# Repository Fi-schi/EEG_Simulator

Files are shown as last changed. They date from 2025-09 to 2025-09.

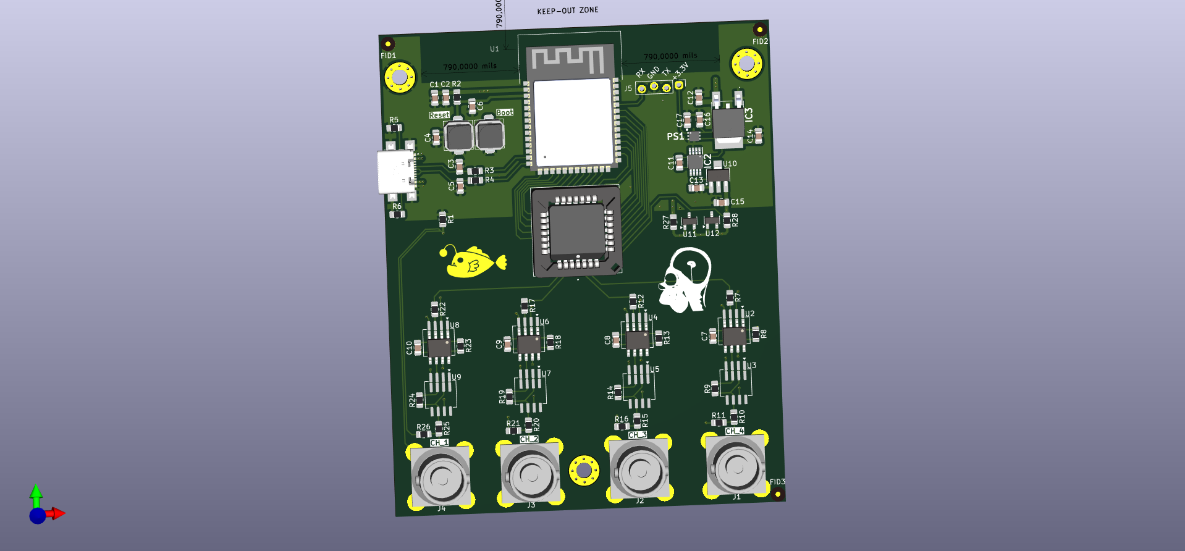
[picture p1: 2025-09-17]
hardware/EEG-Simulator-Platine/EEG-Simulator-Platine.png

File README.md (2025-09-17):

# EEG-Simulator

Ein Projektseminar an der Hochschule Wismar zur **Entwicklung eines
EEG-Signalgenerators**. 
Ziel ist es, eine kompakte, intuitive und didaktisch nutzbare Plattform
zur Erzeugung synthetischer EEG-Signale bereitzustellen.

## Features

-   4 analoge Ausgangskanäle für simultane Signalwiedergabe 
-   Steuerung über einen **ESP32-S3 Mikrocontroller** 
-   Hochauflösender DAC (**DAC8412FPZ**) mit 12-Bit Auflösung 
-   Benutzerfreundliche **Weboberfläche** zur Signalverwaltung 
-   Upload eigener Signaldateien über WLAN 
-   Signale im Mikrovoltbereich durch Tiefpassfilter & Spannungsteiler 
-   Keine zusätzliche Softwareinstallation erforderlich (Bedienung im
    Browser)

## Architektur

-   **Hardware**
    -   ESP32-S3 Mikrocontroller (Steuerung, WLAN, Webserver)
    -   DAC8412FPZ (Digital-Analog-Wandler, 4 Kanäle)
    -   TL071CDR Operationsverstärker (aktive Tiefpassfilter)
    -   Spannungsversorgung über USB-C, mit ±5 V und 3,3 V Regulierung
-   **Software**
    -   Frontend: HTML, CSS, JavaScript (Single Page Application)
    -   Backend: ESP32-Firmware in C++ (PlatformIO, ESPAsyncWebServer)
    -   Dateiverwaltung & Signalzuweisung über Webinterface
    -   DAC-Steuerung und Echtzeit-Signalausgabe

## Getting Started

1.  Platine über **USB-C** mit Strom versorgen 
2.  Verbindung mit dem WLAN **EEGsimulator** (Passwort:
    `EEGsimulator2525`) 
3.  Browser öffnen und `192.168.4.1` eingeben 
4.  Über die Weboberfläche:
    -   Signaldateien (`.txt`) hochladen 
    -   Dateien Kanälen zuweisen 
    -   „Verarbeitung anstoßen" und anschließend „Abspielen" klicken

## Dateiformat für Signale

-   Textdateien mit Zahlenwerten (positive/negative Amplituden) 
-   Automatische Skalierung auf den **12-Bit Wertebereich (0--4095)** 
-   Mapping:
    -   Negative Werte → 0--2047 
    -   Positive Werte → 2048--4095

## Hinweise

-   Für stabile Ausgabe eine saubere Stromversorgung sicherstellen 
-   Signale lassen sich per Oszilloskop überwachen 
-   Änderungen an Reihenfolge oder Kanälen erfordern erneute
    Verarbeitung

## Ausblick

-   Verbesserte analoge Filter (z. B. Sallen-Key) 
-   Optimierte Stromversorgung (LDOs oder Akkubetrieb) 
-   Bibliothek vordefinierter EEG-Signalformen (Alpha-/Beta-Wellen
    etc.) 
-   Live-Visualisierung der Signale direkt im Browser

------------------------------------------------------------------------

Entwickelt von **Johannes Fischer** im Rahmen des Projektseminars an
der **Hochschule Wismar**

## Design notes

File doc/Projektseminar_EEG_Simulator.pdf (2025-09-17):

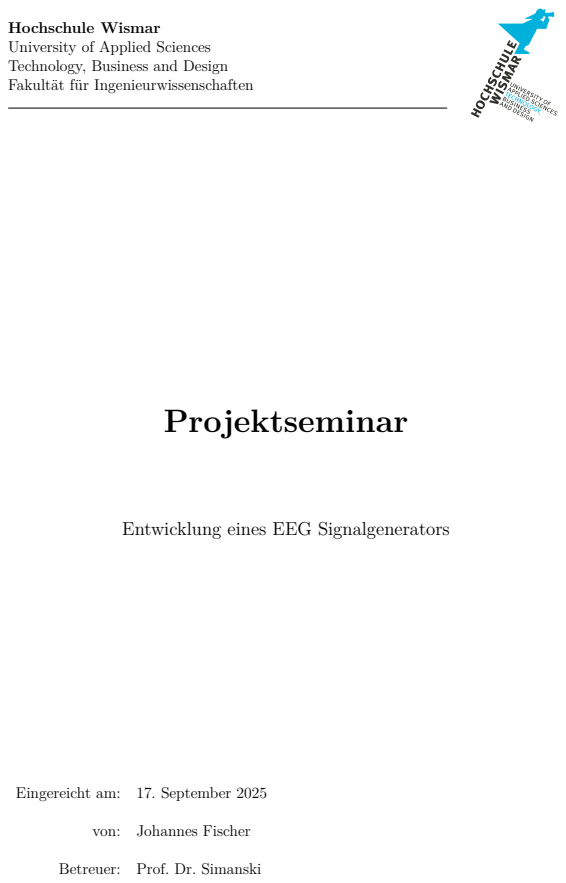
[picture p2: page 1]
Projektseminar

Hochschule Wismar
University of Applied Sciences
Technology, Business and Design
Fakultät für Ingenieurwissenschaften

Entwicklung eines EEG Signalgenerators

Eingereicht am: 17. September 2025

von: Johannes Fischer
Betreuer: Prof. Dr. Simanski

Kurzfassung

Kurzfassung

Im Rahmen des Projektseminars wurde eine Demonstrationsplatine zur Erzeugung synthetischer EEG-Signale entwickelt. Ziel war es, ein kompaktes und intuitiv bedienbares System zu realisieren, das insbesondere im naturwissenschaftlich-technischen Unterricht zum Einsatz kommen kann. Die Signalverarbeitung übernimmt ein ESP32-S3 Mikrocontroller, der über eine parallele Schnittstelle einen hochauflösenden DAC (DAC8412FPZ) ansteuert. Die vier analogen Ausgangskanäle ermöglichen die gleichzeitige Ausgabe mehrerer Signalverläufe. Die Konfiguration der Signale erfolgt benutzerfreundlich über eine integrierte Weboberfläche, die ohne zusätzliche Softwareinstallation über WLAN erreichbar ist. Der Aufbau der Schaltung wurde so gewählt, dass die Signale durch Tiefpassfilter geglättet und über Spannungsteiler optional auf den Mikrovoltbereich skaliert werden können. Während der Erprobung zeigte sich, dass sich die Ausgabequalität durch den Einsatz zusätzlicher Filter- oder Versorgungskomponenten weiter optimieren lässt. Die entwickelte Platine bietet eine solide Basis für didaktische Zwecke sowie eine flexible Plattform für zukünftige Erweiterungen, etwa zur Visualisierung der DAC-Ausgabe im Browser oder zur Einbindung von Signalbibliotheken.

Abstract

In the context of a project seminar, a demonstration printed circuit board (PCB) was developed for the purpose of generating synthetic electroencephalograms (EEGs). The objective of the project was to design a compact and user-friendly system suitable for use in science and engineering education. The generation of signals is facilitated by an ESP32-S3 microcontroller, which governs a high-resolution DAC (DAC8412FPZ) through a parallel interface. It is evident that the four analog output channels facilitate the simultaneous playback of multiple signal patterns. The configuration of the signal is managed through a built-in web interface that is accessible via Wi-Fi and does not require the installation of additional software. The circuit design incorporates low-pass filters for signal smoothing and optional voltage dividers for scaling to microvolt levels. As the testing process unfolded, it became evident that the quality of output could be further enhanced through the implementation of advanced filtration techniques and optimisation of the power supply. The developed system provides a robust foundation for educational applications and a flexible platform for future expansions, such as browser-based signal visualization or the integration of predefined signal libraries.

Inhaltsverzeichnis

### Inhaltsverzeichnis

1 Einleitung | 4
2 Platine | 5
3 Software | 15
4 Bedienung | 18
5 Zusammenfassung und Ausblick | 20
Abbildungsverzeichnis | 22
Selbstständigkeitserklärung | 23

Kapitel 1. Einleitung

### 1 Einleitung

Im Rahmen dieses Projektseminars wurde eine elektronische Schaltung (Platine) entwickelt, die synthetisch generierte EEG-Signale über vier analoge Ausgänge bereitstellen kann. Ziel ist die Bereitstellung eines anschaulichen Demonstrationssystems für den Einsatz im naturwissenschaftlich-technischen Unterricht. Die Signalverarbeitung erfolgt über einen Mikrocontroller, der die digitalen Muster erzeugt und diese über einen Digital-Analog-Wandler (DAC) in analoge Signale umwandelt. Zur Ausgabe stehen vier EEG-Kanäle zur Verfügung, denen die Signale gezielt zugewiesen werden können. Ein weiterer Bestandteil des Projekts ist die Entwicklung eines Webinterfaces, das über die WLAN-Schnittstelle des Mikrocontrollers erreichbar ist. Über die Benutzeroberfläche lassen sich die Signalparameter gezielt einstellen sowie die Kanalzuweisung der Signale verwalten. Zur Visualisierung der generierten Signale wird ein Oszilloskop verwendet, das die analoge Ausgabe in Echtzeit darstellt.

### 1.1 Zielsetzung und Anforderungen

Ziel dieses Kapitels ist die Darstellung der technischen Anforderungen und der strukturellen Umsetzung der entwickelten Platine. Die Schaltung dient als Demonstrationsund Lehrgerät zur Veranschaulichung synthetisch erzeugter EEG-Signale im schulischen oder hochschulischen Unterricht. Kernziel der Platine ist die Erzeugung und analoge Ausgabe von EEG-Signalen über vier getrennte Kanäle. Die Parametrierung der Signale erfolgt über eine browserbasierte Benutzeroberfläche, die ohne zusätzliche Softwareinstallation genutzt werden kann. Die gesamte Steuerung und Ausgabe wird durch einen Mikrocontroller übernommen, der sowohl die Signalverarbeitung als auch die Bereitstellung der Weboberfläche realisiert. Zur Sicherstellung einer realistischen Signalform und zur Rauschunterdrückung kommen ein hochauflösender Digital-Analog-Wandler sowie nachgeschaltete analoge Tiefpassfilter zum Einsatz. Zusätzlich wird das Ausgangssignal über einen Spannungsteiler skaliert, um typische EEG-Signalpegel im Mikrovoltbereich darzustellen. Die folgenden Abschnitte beschreiben die eingesetzten Komponenten, ihre Auswahlkriterien und die Umsetzung auf der entwickelten Platine.

Kapitel 2. Platine

### 2 Platine

### 2.1 Komponentenübersicht

Für die Umsetzung der Platine wurden gezielt Bauteile ausgewählt, die eine zuverlässige Signalverarbeitung sowie eine einfache Integration in ein schulisches Umfeld ermöglichen. Die wichtigsten Hardwarekomponenten sind:
- Mikrocontroller: ESP32-S3 16R8 – steuert die gesamte Signalverarbeitung, erzeugt die digitalen Datenmuster und stellt die Weboberfläche über WLAN bereit.
- Digital-Analog-Wandler (DAC): DAC8412FPZ – ermöglicht die hochauflösende, analoge Ausgabe der zuvor digital berechneten EEG-Signale auf vier unabhängigen Kanälen.
- Operationsverstärker: TL071CDR – dient als aktiver Tiefpassfilter (1. Ordnung) mit einer Verstärkung von 1 zur Glättung der analogen Ausgangssignale.
- Spannungsversorgung:
– NCV1117DT50: Linearregler zur Bereitstellung einer stabilisierten 5-V-Spannung für den DAC und nachgeschaltete Stufen.
– USB-C-Buchse: Dient sowohl der Stromversorgung als auch der optionalen Datenverbindung während der Entwicklung.

### 2.1.1 Hardwarekonzept

Der Mikrocontroller ESP32-S3 16R8 bildet das zentrale Steuerelement der Platine. Er verfügt über zwei Prozessorkerne, wodurch sich die Verarbeitung von Signalmustern und die Bereitstellung der Weboberfläche auf getrennte Kerne verteilen lassen. Mit 16 MB integriertem Flash-Speicher bietet er zudem ausreichend Kapazität zur Ablage von Firmware, Webdateien und Nutzdaten.
Für die analoge Signalausgabe wird der Digital-Analog-Wandler DAC8412FPZ von Analog Devices eingesetzt. Dieser 12-Bit-DAC besitzt vier voneinander unabhängige Ausgänge und wird über eine parallele 16-Bit-Schnittstelle angesteuert. Die

Ansteuerung ermöglicht eine hohe Datenrate und unterstützt somit eine nahezu echtzeitfähige Signalübertragung.
Zur Nachbearbeitung der DAC-Ausgabe wird ein aktiver Tiefpassfilter auf Basis des Operationsverstärkers TL071CDR verwendet. Dieser glättet die Treppenspannung des DACs und unterdrückt hochfrequentes Rauschen, um ein möglichst sauberes analoges Ausgangssignal zu erzeugen.
Die Spannungsversorgung der Komponenten wird durch mehrere Regler bereitgestellt: Ein Linearregler (LDO) liefert 5 V für den DAC und nachgeschaltete Stufen, ein weiterer LDO stellt 3,3 V für den Mikrocontroller bereit. Zusätzlich erzeugt ein invertierender DC/DC-Wandler die negative Versorgungsspannung, sodass der DAC und die Operationsverstärker symmetrisch mit ±5 V betrieben werden können.

### 2.2 Schaltungsdesign

### 2.2.1 Gesamtüberblick

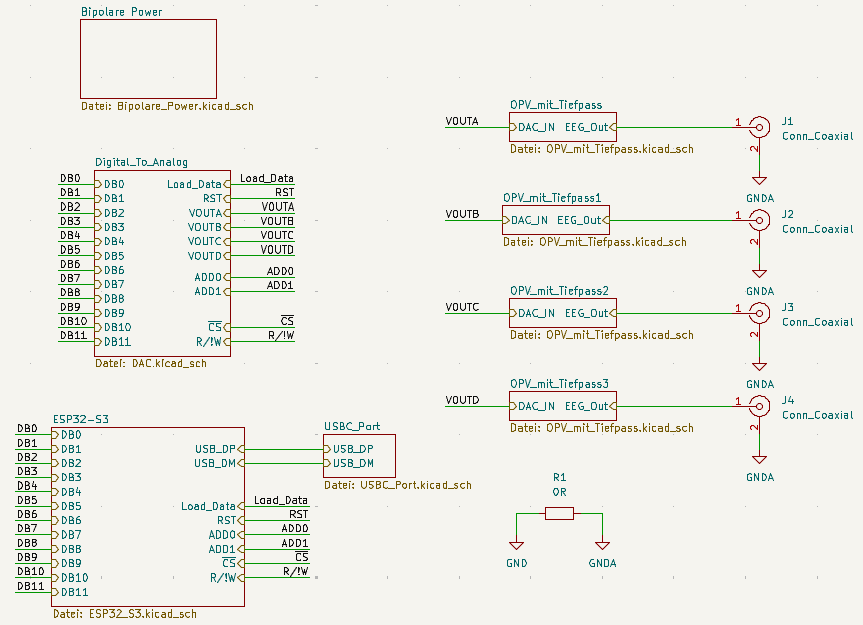
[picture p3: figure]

Abbildung 1: Gesamtübersicht der Platine

Die Schaltung ist modular aufgebaut und in mehrere funktionale Blöcke gegliedert, die jeweils klar definierte Aufgabenbereiche abdecken:
- Mikrocontroller-Block: Beinhaltet den ESP32-S3 16R8, der die gesamte Steuerlogik sowie die Webschnittstelle übernimmt.
- DAC-Block: Umfasst den DAC8412FPZ zur Umwandlung der digitalen Signalmuster in analoge Ausgangssignale.
- Operationsverstärker-Block: Realisiert die analoge Filterung der DAC-Ausgänge mittels aktiver Tiefpassfilter.
- Spannungsversorgungsblock: Stellt alle benötigten Spannungen bereit (5V, ±5V, 3,3V) inklusive Referenzspannungen.
- USB-Block: Dient als Schnittstelle zur Stromversorgung über USB-C.

### 2.2.2 Mikrocontroller-Block

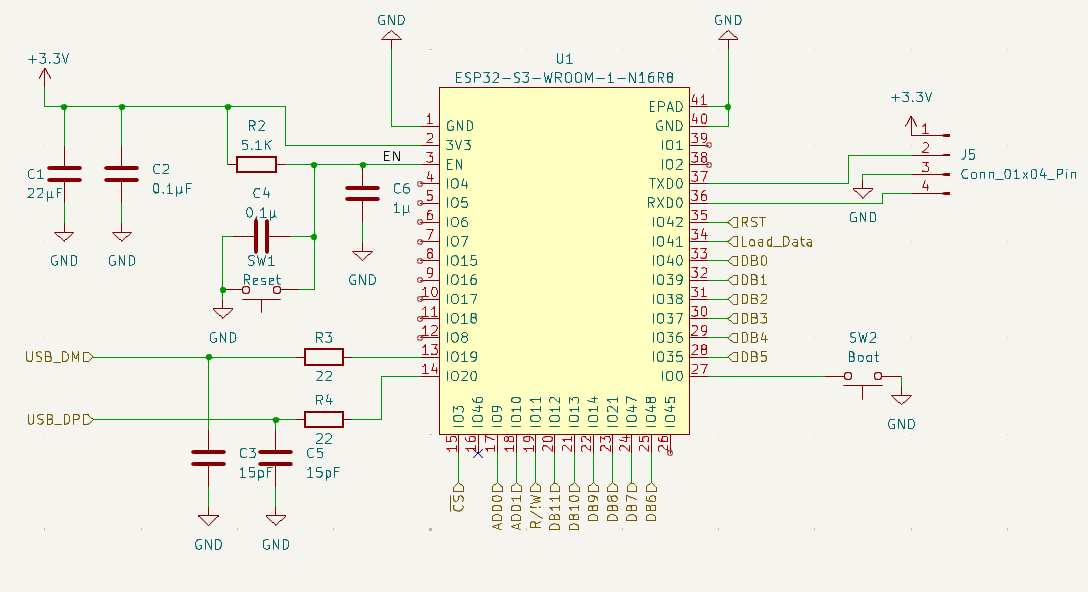
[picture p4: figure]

Abbildung 2: Mikrocontroller-Block der Platine

Der Mikrocontroller-Block bildet die zentrale Steuereinheit der Platine. Herzstück ist der ESP32-S3 16R8, der sowohl die Erzeugung der digitalen EEG-Signalmuster als auch die Bereitstellung der Weboberfläche übernimmt. Die Kommunikation mit dem DAC erfolgt über eine 16-Bit-Parallelschnittstelle, wodurch eine hohe Übertragungsrate und geringe Latenz erreicht werden. Die Programmierung des Mikrocontrollers erfolgt in C++ unter Verwendung der Arduino-Entwicklungsumgebung, ergänzt durch das Build-System PlatformIO. Neben der Echtzeitsteuerung der Signalausgabe ist der ESP32 auch für das Dateihandling sowie die Konfigurationslogik zuständig.

### 2.2.3 DAC-Block

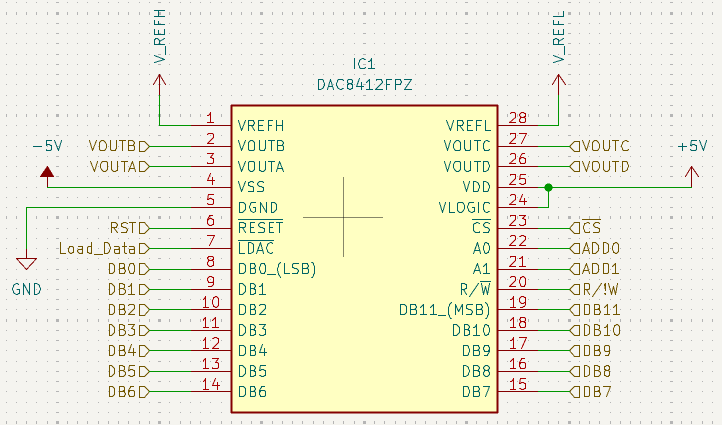
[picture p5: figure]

Abbildung 3: DAC-Block der Platine

Der DAC-Block umfasst den Digital-Analog-Wandler DAC8412FPZ von Analog Devices. Dieser 12-Bit-DAC ist für die Umwandlung der vom Mikrocontroller erzeugten digitalen Signalmuster in analoge Spannungen verantwortlich. Die Ansteuerung erfolgt über eine parallele 16-Bit-Schnittstelle, bei der alle relevanten Datenbits gleichzeitig übertragen werden. Diese Übertragungsart ermöglicht eine hohe Datentransferrate bei gleichzeitig geringer Latenz und eignet sich daher besonders für zeitkritische Anwendungen wie die synchrone Ausgabe mehrerer Kanäle. Der DAC8412FPZ stellt vier voneinander unabhängige Ausgänge bereit. Jeder dieser Kanäle kann ein separates, kontinuierliches EEG-Signal ausgeben. Die Zuordnung der Signaldaten zu den Ausgängen erfolgt über die Softwarelogik im Mikrocontroller. Die resultierenden Spannungen an den DAC-Ausgängen werden anschließend in den analogen Nachbearbeitungsblock überführt.

### 2.2.4 Operationsverstärker-Block

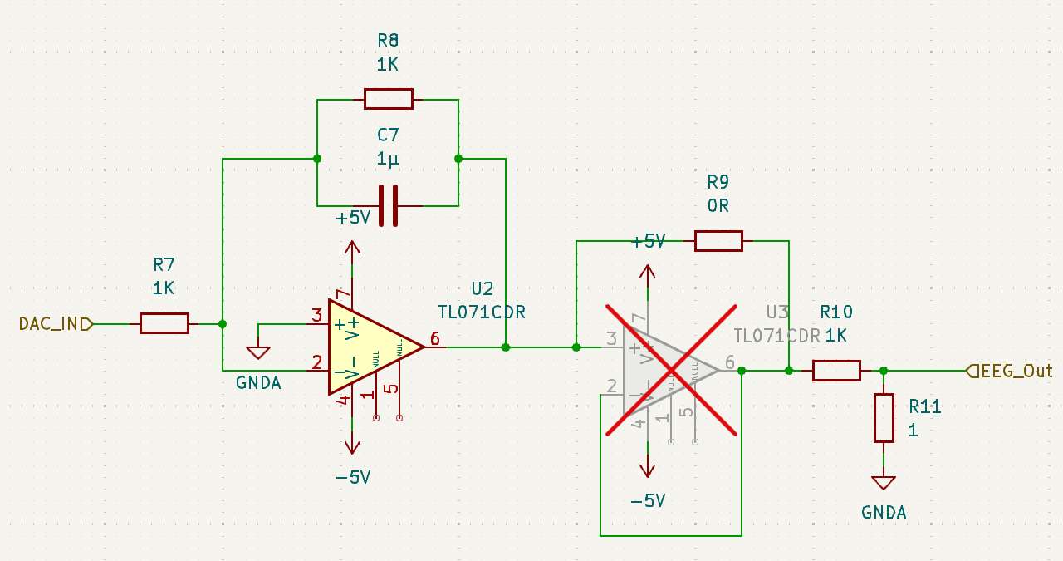
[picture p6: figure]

Abbildung 4: Operationsverstärker-Block der Platine

Der Operationsverstärker-Block dient der analogen Nachbearbeitung der vom Digital-Analog-Converter (DAC) bereitgestellten Ausgangssignale. Zum Einsatz kommt der TL071CDR, ein rauschoptimierter Operationsverstärker, der in dieser Anwendung als aktiver Tiefpassfilter erster Ordnung konfiguriert ist. Die Hauptfunktion besteht in der Glättung der Signale und der Unterdrückung hochfrequenter Störanteile. Die Verstärkung des Filters ist auf 1 eingestellt, um die Signalform nicht zu verändern und gleichzeitig die Spannungsausgabe im gewünschten Millivolt-Bereich zu halten. Optional kann ein zusätzlicher Operationsverstärker bestückt werden, der als Spannungsfolger (Buffer) wirkt. Dieser dient zur Reduzierung der Ausgangsimpedanz und kann insbesondere bei empfindlichen Messeingängen oder längeren Leitungswegen zur Verbesserung der Signalqualität beitragen. In der Standardkonfiguration ist dieser Pfad durch einen Jumper überbrückt und nicht bestückt.

### 2.2.5 Spannungsversorgung

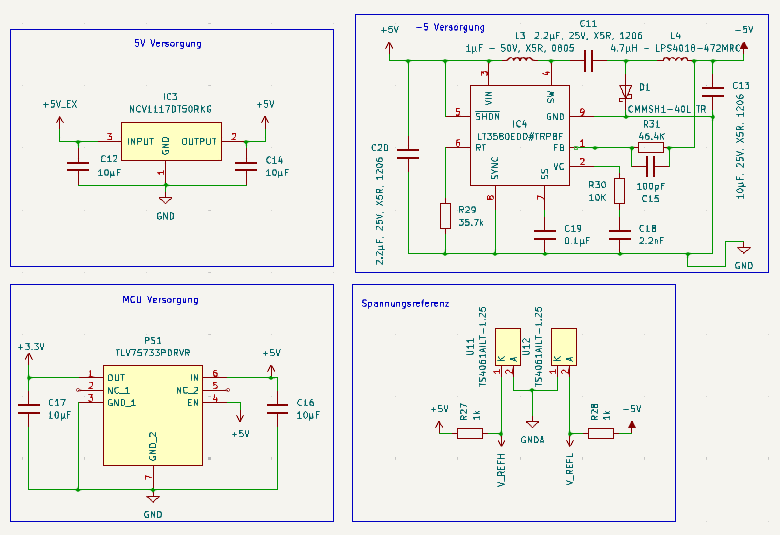
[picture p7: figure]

Abbildung 5: Spannungsversorgungsblock der Platine

Die Spannungsversorgung der Platine erfolgt primär über eine USB-Schnittstelle, die eine Eingangsspannung von 5 V bereitstellt. Diese Spannung wird durch den Linearregler NCV1117DT50RKG stabilisiert und zur Versorgung des DACs sowie der analogen Ausgangsstufen verwendet. Für die Versorgung des Mikrocontrollers steht ein separater Low-Dropout-Regler (TLV75733PDRVR) zur Verfügung, der die benötigten 3,3 V bereitstellt. Da der DAC DAC8412FPZ eine symmetrische Versorgung von ±5 V erfordert, wird zusätzlich ein invertierender DC/DC-Wandler (LT3580EDD) eingesetzt. Dieser erzeugt aus der 5 V-Versorgungsspannung eine negative Spannung von –5 V, die ebenfalls zur Versorgung der Operationsverstärker verwendet wird. Zudem benötigt der DAC eine präzise Referenzspannung. Diese wird über zwei Shunt-Referenzbausteine vom Typ TS4061AILT-1.25 realisiert und stellt eine stabile ±1,25 V-Referenz zur Verfügung. Diese Referenz ist entscheidend für die Genauigkeit der analogen Ausgangssignale.

### 2.2.6 USB-Block

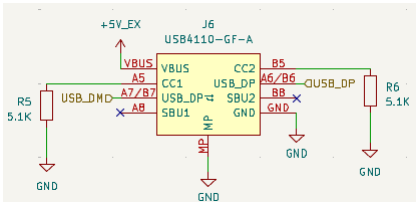
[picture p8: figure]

Abbildung 6: USB-Block der Platine

Der USB-Block bildet die primäre Schnittstelle zur Stromversorgung der Platine. Über einen USB-C-Anschluss wird eine standardisierte 5 V-Spannung bereitgestellt, die anschließend im Spannungsversorgungsblock weiter aufbereitet wird. Zusätzlich enthält der Block grundlegende Schutz- und Filterelemente zur Absicherung der Versorgungsspannung gegen Spannungsspitzen und Verpolung. Optional kann die USB-Schnittstelle auch zur Datenübertragung mit dem Mikrocontroller verwendet werden, beispielsweise während der Programmierung oder zum Debugging über die serielle Schnittstelle. In der typischen Anwendung wird die Kommunikation jedoch vollständig über die WLAN-Funktion des ESP32 abgewickelt.

### 2.3 Layout und PCB-Design

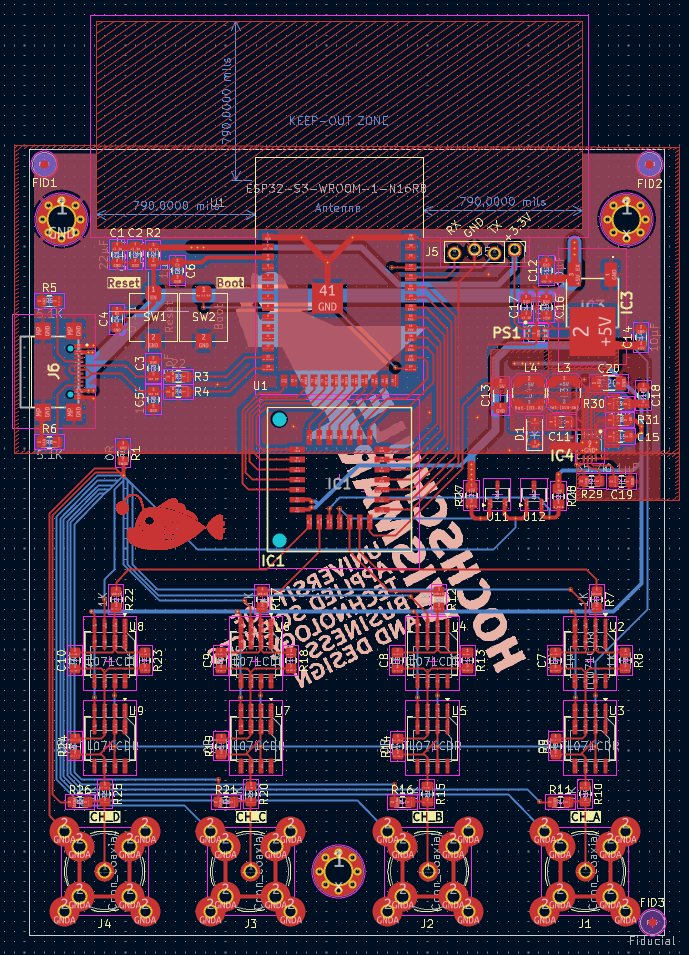
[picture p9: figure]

Abbildung 7: Layout der Platine

Das PCB-Design wurde mit Fokus auf klare Signalführung, minimale Störanfälligkeit und eine strukturierte Blocktrennung umgesetzt. Die zweilagige Leiterplatte gliedert sich logisch in funktionale Bereiche, wobei sowohl die digitale Steuerung als auch die analogen Ausgangspfade übersichtlich und EMV-gerecht angeordnet sind. Der Mikrocontroller (ESP32-S3) befindet sich im oberen Bereich der Platine und kommuniziert über eine parallele Busanbindung mit dem darunter angeordneten

DAC8412FPZ. Die digitalen Steuersignale sind dabei als kurze, breit geführte Leitungen ausgeführt, um Reflexionen und Timing-Probleme zu minimieren. Die vier analogen Ausgangskanäle befinden sich im unteren Bereich der Platine. Jeder Kanal verfügt über eine eigene Tiefpassfilterstufe sowie individuell geführte Ausgänge, die über identisch dimensionierte Leitungen auf korrekte Impedanz und Symmetrie geachtet wurden. Die Versorgungsspannungen verlaufen sternförmig von der zentralen Spannungsaufbereitung aus, wobei Filterkondensatoren lokal an jedem Block platziert sind. Besonders im Bereich der symmetrischen Versorgung (±5 V) und der Referenzspannungen wurde auf kurze Wege, Masseführung und Potentialtrennung geachtet. Zudem wurde eine definierte „Keep-Out-Zone“ um die Antenne des ESP32 ausgewiesen, um Störungen im WLAN-Bereich zu vermeiden.

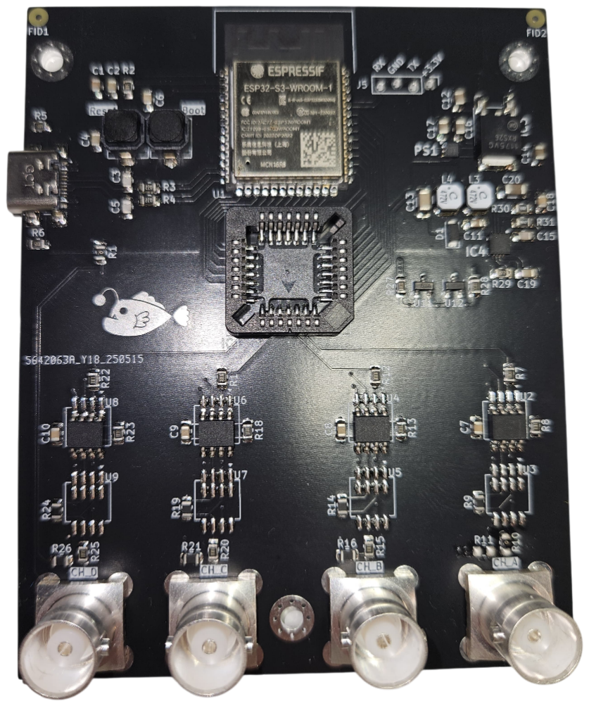
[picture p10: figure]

Abbildung 8: Bestückte Platine

Kapitel 3. Software

### 3 Software

Die Software des Systems gliedert sich in zwei Hauptkomponenten: das Webinterface mit zugehörigem Webserver sowie die Verarbeitungseinheit zur Steuerung des DAC. In diesem Kapitel wird der Aufbau beider Softwareteile erläutert. Die konkrete Bedienung der Benutzeroberfläche und Abläufe aus Anwendersicht werden im Anschlusskapitel Bedienung beschrieben.

### 3.1 Frontend: Webinterface

Das Frontend ist eine lokal vom Mikrocontroller bereitgestellte Weboberfläche zur Steuerung und Überwachung des Systems. Die grafische Benutzeroberfläche wurde mit HTML, CSS und JavaScript umgesetzt und als sogenannte Single Page Application (SPA) realisiert. Ziel war eine moderne, intuitive und plattformunabhängige Steuerung über das Netzwerk.

### 3.1.1 Struktur

Die Weboberfläche besteht aus folgenden Komponenten:
- Einem Kopfbereich mit Logo und Titel
- Einer Tab-Navigation zur Auswahl verschiedener Funktionsbereiche
- Inhaltsbereiche für Datei-Uploads, Dateiverwaltung und Statusanzeigen
- Upload-Felder zur Übertragung von Dateien an den Mikrocontroller
- Fortschrittsanzeigen für laufende Dateiübertragungen
- Menüs zur Kanalzuweisung von Dateien

Kapitel 3. Software

### 3.1.2 Funktion

Das JavaScript im Frontend übernimmt folgende Aufgaben:
- Initialisierung und Abfrage von Systemstatus (z.,B. Speicherplatz, Dateiliste)
- Regelmäßige Aktualisierung des Speicherstatus (alle 5 Sekunden)
- Hochladen von Dateien per Datei-Dialog oder Drag-and-Drop
- Anzeige des Uploadfortschritts für jede Datei
- Interaktive Zuordnung von Dateien zu DAC-Kanälen
Die gesamte Kommunikation mit dem ESP32 erfolgt asynchron per HTTP.

### 3.2 Backend: Mikrocontroller-Firmware

Das Backend ist als Firmware auf einem ESP32-S3 Mikrocontroller umgesetzt. Es wurde in C++ mit PlatformIO entwickelt und ist modular aufgebaut. Die Firmware übernimmt sowohl die Netzwerkschnittstelle (Webserver), die Dateiverwaltung als auch die Steuerung der Hardware.

### 3.2.1 Systemaufbau

Die Firmware gliedert sich in folgende Hauptbestandteile:
- main.cpp: Initialisierung von WLAN, Dateisystem (SPIFFS) und Webserver
- Server.cpp: Bereitstellung der HTTP-Routen für Datei-Uploads und Speicherfunktionen
- Spannungswandlung.cpp: Verarbeitung und Umwandlung der digitalen Werte für den DAC
- PinMapping.cpp: Zuordnung der Funktionen zu den verwendeten GPIO-Pins

### 3.2.2 Webserverfunktionen

Der Webserver basiert auf der Bibliothek ESPAsyncWebServer und bietet:
- Bereitstellung der HTML-/JS-Dateien aus dem SPIFFS-Dateisystem
- Empfang und Speicherung hochgeladener Dateien
- Auslesen des freien Speicherplatzes
- Steuerung von GPIOs und Ausgabe an den DAC

Kapitel 3. Software

### 3.2.3 Datenverarbeitung und DAC-Steuerung

Sobald der Benutzer im Webinterface den Befehl zur Verarbeitung auslöst, wird der Inhalt der ausgewählten Textdateien in strukturierter Reihenfolge verarbeitet. Die Zahlenwerte in den Dateien werden extrahiert und in Kanal-spezifischen Arrays abgelegt. Dabei erfolgt eine Skalierung auf den 12-Bit-Wertebereich (0 bis 4095) des DAC, wobei negative Werte (im bipolaren Modus) auf 0 bis 2047, positive auf 2048 bis 4095 abgebildet werden.
Die Umwandlung erfolgt bitweise: Jeder Wert wird in ein 8-Bit-Muster übersetzt, das über entsprechende GPIO-Pins an den DAC übermittelt wird. Eine Taktsynchronisation stellt sicher, dass jeder Wert korrekt übergeben und konvertiert wird. Die Ausgabe erfolgt mit fester Frequenz, um eine gleichmäßige Signalform zu erzeugen.

Kapitel 4. Bedienung

### 4 Bedienung

Die Bedienung der EEG-Demonstrationsplatine erfolgt vollständig über eine browserbasierte Weboberfläche, die vom Mikrocontroller bereitgestellt wird. Es ist keine zusätzliche Softwareinstallation notwendig – ein aktueller Webbrowser genügt. Im Folgenden wird der typische Bedienablauf Schritt für Schritt beschrieben.

### 4.1 Verbindung zur Platine

Nach dem Einschalten der Platine erzeugt der ESP32-S3 einen eigenen WLAN-Hotspot mit dem Netzwerknamen EEGsimulator und dem Netzwerkpasswort EEGsimulator2525. Nutzerinnen und Nutzer verbinden sich mit diesem WLAN, das keine Internetverbindung benötigt. Anschließend kann die Weboberfläche über die IP-Adresse 192.168.4.1 im Browser geöffnet werden.

### 4.2 Weboberfläche

Die Weboberfläche ist in mehrere Bereiche unterteilt:
- Dateiupload: Ermöglicht das Hochladen von .txt-Dateien, die Zahlenwerte zur DAC-Ausgabe enthalten. Der Upload erfolgt per Drag-and-Drop oder über einen Dateiauswahldialog.
- Dateiverwaltung: Zeigt eine Liste aller hochgeladenen Dateien an. Die Reihenfolge kann per Drag-and-Drop verändert werden und bestimmt die spätere Abspielreihenfolge.
- Kanalauswahl: Jeder Datei kann ein DAC-Ausgangskanal zugewiesen werden (A bis D). Die Zuordnung erfolgt über ein Auswahlmenü neben dem Dateinamen.
- Signalverarbeitung: Durch Auswahl und anschließenden Klick auf den Button „Verarbeitung anstoßen“ wird der Inhalt der gewählten Dateien eingelesen, auf korrekte Struktur überprüft und für die DAC-Ausgabe vorbereitet.

Kapitel 4. Bedienung

- Signalwiedergabe: Der Button „Abspielen“ startet die Ausgabe der Signale über die vier DAC-Kanäle. Die Daten werden dabei taktgenau an den DAC übertragen und in analoge Spannungen gewandelt.

### 4.3 Ablauf der Signalerzeugung

Nach dem Hochladen und der Auswahl der relevanten Dateien läuft die Erzeugung der EEG-Signale wie folgt ab:
1. Die enthaltenen Zahlenwerte werden aus den Textdateien extrahiert.
2. Negative und positive Werte werden auf den 12-Bit-Wertebereich des DACs abgebildet (0–2047 für negativ, 2048–4095 für positiv).
3. Die konvertierten Werte werden kanalweise in interne Speicherarrays geladen.
4. Die Ausgabefrequenz bestimmt das zeitliche Intervall zwischen den DAC-Werten.
5. Bei Klick auf „Abspielen“ beginnt die kontinuierliche, synchrone Ausgabe.

### 4.4 Hinweise zur Verwendung

- Nach Änderungen an der Dateireihenfolge oder Kanalauswahl muss die Verarbeitung erneut angestoßen werden.
- Eine stabile Stromversorgung über USB-C ist für die gleichmäßige Ausgabe unerlässlich.
- Die Signale können mit einem Oszilloskop am Ausgang überwacht werden.

Kapitel 5. Zusammenfassung und Ausblick

### 5 Zusammenfassung und Ausblick

### 5.1 Zusammenfassung

Im Rahmen dieses Projekts wurde eine funktionsfähige Demonstrationsplatine zur Erzeugung synthetischer EEG-Signale entwickelt. Ziel war es, ein intuitiv bedienbares und technisch robustes Gerät für den Einsatz im Unterricht bereitzustellen. Die entwickelte Schaltung basiert auf einem ESP32-S3 Mikrocontroller in Kombination mit einem hochauflösenden DAC (DAC8412FPZ). Über vier unabhängige Ausgänge können benutzerdefinierte Signale analog ausgegeben und über Operationsverstärker geglättet werden. Die Parametrierung erfolgt über eine browserbasierte Weboberfläche, die vollständig ohne zusätzliche Softwareinstallation auskommt. Während der Testphase zeigten sich einige Einschränkungen: Die vom invertierenden DC/DC-Wandler erzeugte negative Versorgungsspannung enthielt ein störendes hochfrequentes Signal. Dieses lässt sich jedoch durch einen nachgeschalteten Low-Dropout-Regler (LDO) wirksam unterdrücken. Alternativ wurde erfolgreich eine Versorgung über zwei symmetrisch verschaltete Lithium-Akkus getestet, wodurch die Störungen vollständig vermieden wurden.
Die Signalqualität im Mikrovoltbereich war zunächst stark von Rauschanteilen überlagert. Mittels spektraler Analyse (FFT) konnte das Nutzsignal jedoch nachgewiesen werden. Durch das Überbrücken des Spannungsteilers mittels 0-Ohm-Jumpern lässt sich das Signal alternativ auch im Millivoltbereich nutzen, was eine deutlich einfachere Auswertung per Oszilloskop ermöglicht.

### 5.2 Ausblick

Die derzeitige Version erfüllt alle grundlegenden Anforderungen an eine signalgebende EEG-Demoplatine. Dennoch ergeben sich mehrere sinnvolle Erweiterungs- und Optimierungsmöglichkeiten:

Kapitel 5. Zusammenfassung und Ausblick

- Verbesserung der Filterung: Der Einsatz eines höherwertigen analogen Tiefpassfilters (z. B. zweiter Ordnung oder Sallen-Key-Topologie) könnte die Rauschunterdrückung weiter verbessern. Dies muss jedoch experimentell verifiziert werden.
- Stromversorgung: Eine saubere Glättung der bipolare Versorgung über LDOs oder Versorgung mittels Akkus wäre langfristig stabiler als ein DC/DC-Wandler.
- Signalbibliothek: Eine optionale, nicht im Projekt enthaltene Sammlung vordefinierter Signalformen (z.,B. Alpha- oder Betawellen) könnte zukünftig über die Weboberfläche eingebunden werden.
- Live-Visualisierung: Eine grafische Darstellung der aktuellen DAC-Ausgabe direkt auf der Weboberfläche würde die Bedienung deutlich intuitiver gestalten. Dadurch könnten Nutzerinnen und Nutzer die Signalform in Echtzeit mitverfolgen, ohne auf externe Messgeräte wie ein Oszilloskop angewiesen zu sein. Insgesamt bietet die entwickelte Platine eine solide Grundlage für den universitären Einsatz und stellt eine flexible Plattform für weitere didaktische und technische Weiterentwicklungen dar.

Abbildungsverzeichnis

### Abbildungsverzeichnis

1 | Gesamtübersicht der Platine | 7
2 | Mikrocontroller-Block der Platine | 8
3 | DAC-Block der Platine | 9
4 | Operationsverstärker-Block der Platine | 10
5 | Spannungsversorgungsblock der Platine | 11
6 | USB-Block der Platine | 12
7 | Layout der Platine | 13
8 | Bestückte Platine | 14

Selbstständigkeitserklärung

### Selbstständigkeitserklärung

Hiermit erkläre ich, dass ich die vorliegende Arbeit selbständig verfasst und keine anderen als die angegebenen Hilfsmittel benutzt habe. Die Stellen der Arbeit, die anderen Quellen im Wortlaut oder dem Sinn nach entnommen wurden, sind durch Angaben der Herkunft kenntlich gemacht. Dies gilt auch für Zeichnungen, Skizzen, bildliche Darstellungen sowie für Quellen aus dem Internet.
Ich erkläre ferner, dass ich die vorliegende Arbeit in keinem anderen Prüfungsverfahren als Prüfungsarbeit eingereicht habe oder einreichen werde.
Die eingereichte schriftliche Arbeit entspricht der elektronischen Fassung. Ich stimme zu, dass eine elektronische Kopie gefertigt und gespeichert werden darf, um eine Überprüfung mittels Anti-Plagiatssoftware zu ermöglichen.

Ort, Datum Unterschrift

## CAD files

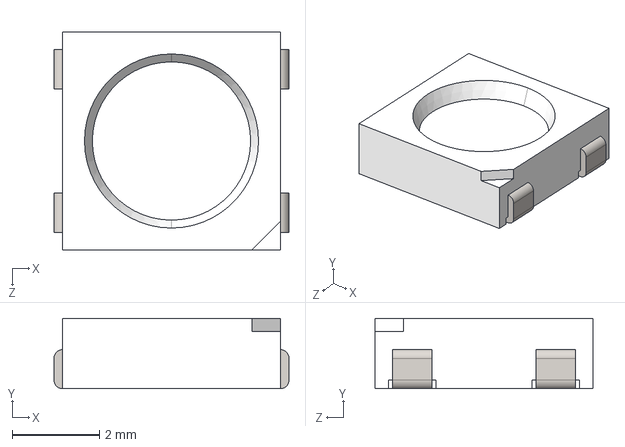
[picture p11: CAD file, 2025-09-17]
hardware/EEG-Simulator-Platine/COM-16346.stp
5.40 x 1.62 x 5.00 mm

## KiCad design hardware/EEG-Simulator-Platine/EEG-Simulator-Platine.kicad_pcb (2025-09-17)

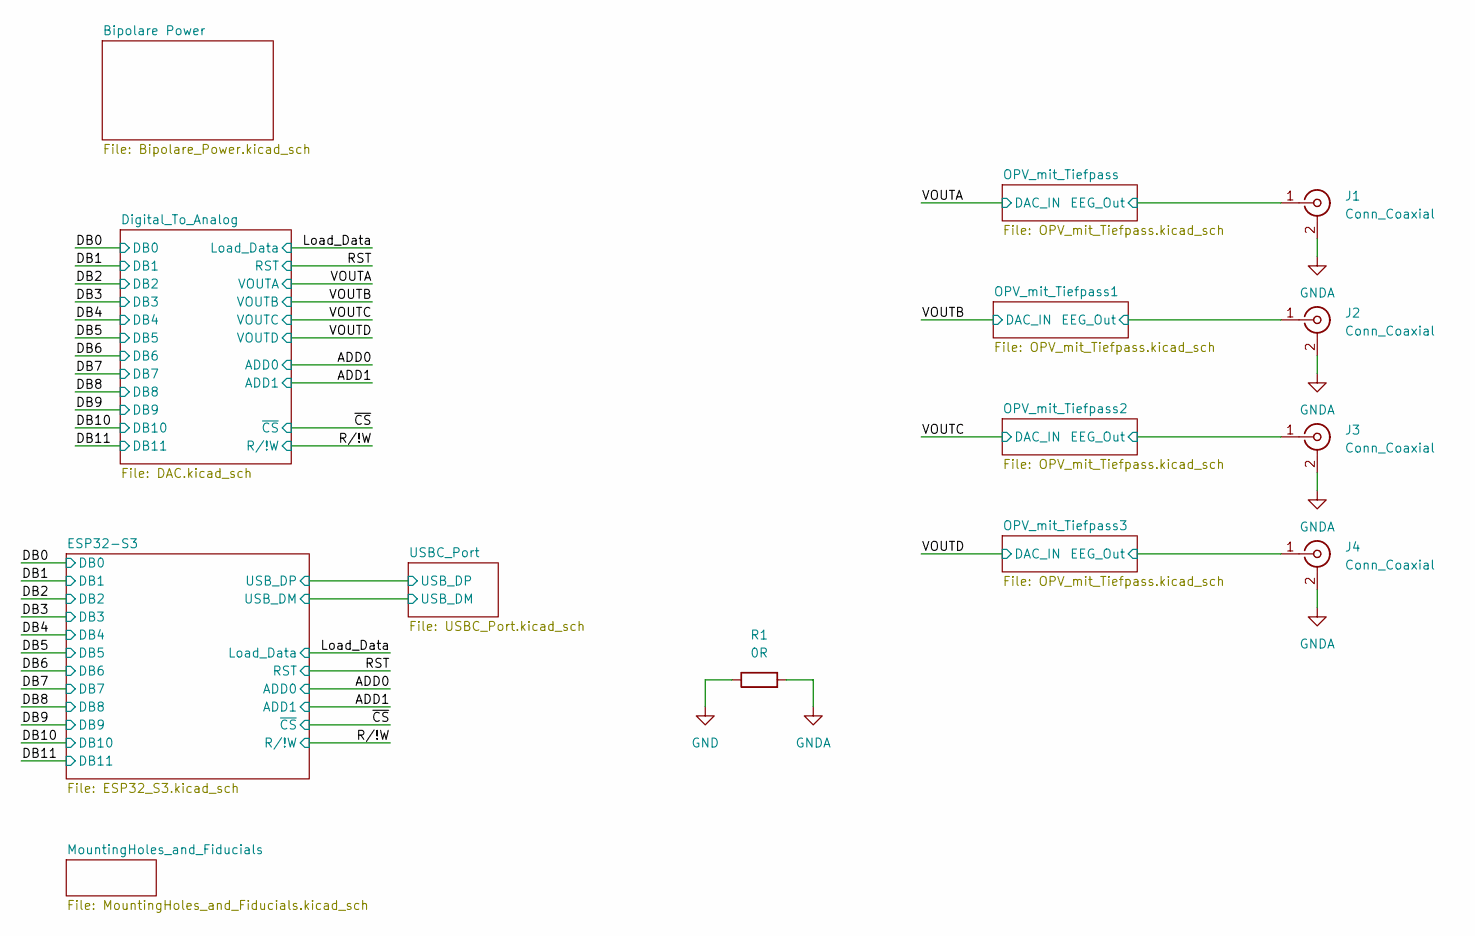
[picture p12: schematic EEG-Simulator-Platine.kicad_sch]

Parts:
J1, J2, J3, J4: Conn_Coaxial; BNC_THT_Socket
R1: 0R; R_0805_2012Metric_Pad1.20x1.40mm_HandSolder

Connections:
/OPV_mit_Tiefpass1/EEG_Out: J2.1 (In); also elsewhere on the board
/OPV_mit_Tiefpass2/EEG_Out: J3.1 (In); also elsewhere on the board
/OPV_mit_Tiefpass3/EEG_Out: J4.1 (In); also elsewhere on the board
/OPV_mit_Tiefpass/EEG_Out: J1.1 (In); also elsewhere on the board
GND: R1.1; also elsewhere on the board
GNDA: J1.2 (Ext), J2.2 (Ext), J3.2 (Ext), J4.2 (Ext), R1.2; also elsewhere on the board

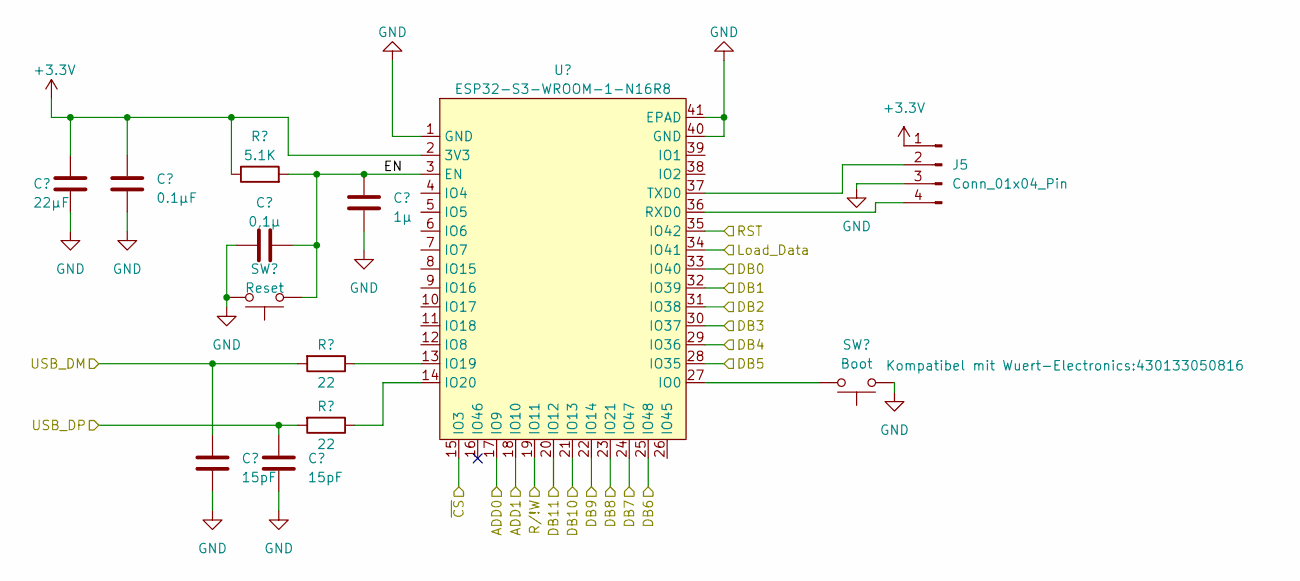
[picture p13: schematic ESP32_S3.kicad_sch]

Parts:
C1: 22µF; C_0805_2012Metric_Pad1.18x1.45mm_HandSolder
C2: 0.1µF; C_0805_2012Metric_Pad1.18x1.45mm_HandSolder
C3, C5: 15pF; C_0805_2012Metric_Pad1.18x1.45mm_HandSolder
C4: 0,1µ; C_0805_2012Metric_Pad1.18x1.45mm_HandSolder
C6: 1µ; C_0805_2012Metric_Pad1.18x1.45mm_HandSolder
J5: Conn_01x04_Pin; Steckerleiste_1x4_2,54mm
R2: 5.1K; R_0805_2012Metric_Pad1.20x1.40mm_HandSolder
R3, R4: 22; R_0805_2012Metric_Pad1.20x1.40mm_HandSolder
SW1: Reset; Takt_Schalter_Aliexpress
SW2: Boot; Takt_Schalter_Aliexpress
U1: ESP32-S3-WROOM-1-N16R8

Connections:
+3.3V: C1.1, C2.1, J5.1, R2.1, U1.2 (3V3); also elsewhere on the board
/ADD0: U1.17 (IO9); also elsewhere on the board
/ADD1: U1.18 (IO10); also elsewhere on the board
/DB0: U1.33 (IO40); also elsewhere on the board
/DB1: U1.32 (IO39); also elsewhere on the board
/DB2: U1.31 (IO38); also elsewhere on the board
/DB3: U1.30 (IO37); also elsewhere on the board
/DB4: U1.29 (IO36); also elsewhere on the board
/DB5: U1.28 (IO35); also elsewhere on the board
/DB6: U1.25 (IO48); also elsewhere on the board
/DB7: U1.24 (IO47); also elsewhere on the board
/DB8: U1.23 (IO21); also elsewhere on the board
/DB9: U1.22 (IO14); also elsewhere on the board
/DB10: U1.21 (IO13); also elsewhere on the board
/DB11: U1.20 (IO12); also elsewhere on the board
/ESP32-S3/EN: C4.2, C6.1, R2.2, SW1.1, U1.3 (EN)
/ESP32-S3/USB_DM: C3.1, R3.2; also elsewhere on the board
/ESP32-S3/USB_DP: C5.1, R4.2; also elsewhere on the board
/Load_Data: U1.34 (IO41); also elsewhere on the board
/RST: U1.35 (IO42); also elsewhere on the board
/R/!W: U1.19 (IO11); also elsewhere on the board
/~CS: U1.15 (IO3); also elsewhere on the board
GND: C1.2, C2.2, C3.2, C4.1, C5.2, C6.2, J5.3, SW1.2, SW2.2, U1.1 (GND), U1.40 (GND), U1.41 (EPAD); also elsewhere on the board
unnamed: J5.2, U1.37 (TXD0)
unnamed: J5.4, U1.36 (RXD0)
unnamed: SW2.1, U1.27 (IO0)
unnamed: R3.1, U1.13 (IO19)
unnamed: R4.1, U1.14 (IO20)

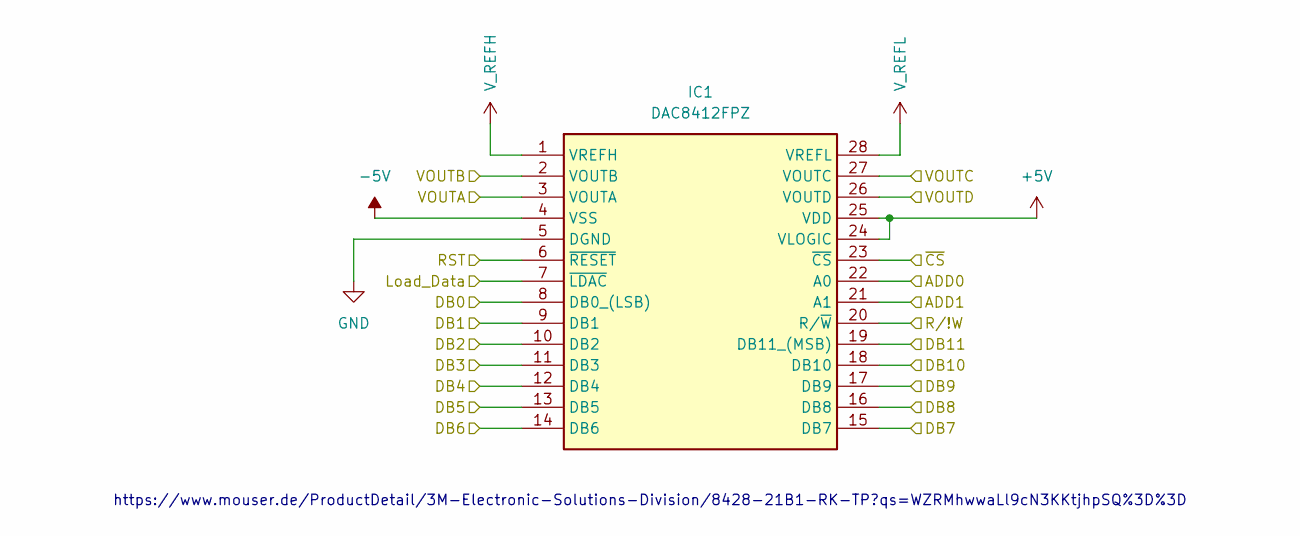
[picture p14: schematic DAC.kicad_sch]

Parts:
IC1: DAC8412FPZ; 842821B1RKTP; Mouser Part Number 584-DAC8412FPZ

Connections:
+5V: IC1.24 (VLOGIC), IC1.25 (VDD); also elsewhere on the board
-5V: IC1.4 (VSS); also elsewhere on the board
/ADD0: IC1.22 (A0); also elsewhere on the board
/ADD1: IC1.21 (A1); also elsewhere on the board
/DB0: IC1.8 (DB0_(LSB)); also elsewhere on the board
/DB1: IC1.9 (DB1); also elsewhere on the board
/DB2: IC1.10 (DB2); also elsewhere on the board
/DB3: IC1.11 (DB3); also elsewhere on the board
/DB4: IC1.12 (DB4); also elsewhere on the board
/DB5: IC1.13 (DB5); also elsewhere on the board
/DB6: IC1.14 (DB6); also elsewhere on the board
/DB7: IC1.15 (DB7); also elsewhere on the board
/DB8: IC1.16 (DB8); also elsewhere on the board
/DB9: IC1.17 (DB9); also elsewhere on the board
/DB10: IC1.18 (DB10); also elsewhere on the board
/DB11: IC1.19 (DB11_(MSB)); also elsewhere on the board
/Load_Data: IC1.7 (~LDAC); also elsewhere on the board
/RST: IC1.6 (~RESET); also elsewhere on the board
/R/!W: IC1.20 (R/~W); also elsewhere on the board
/VOUTA: IC1.3 (VOUTA); also elsewhere on the board
/VOUTB: IC1.2 (VOUTB); also elsewhere on the board
/VOUTC: IC1.27 (VOUTC); also elsewhere on the board
/VOUTD: IC1.26 (VOUTD); also elsewhere on the board
/~CS: IC1.23 (~CS); also elsewhere on the board
GND: IC1.5 (DGND); also elsewhere on the board
V_REFH: IC1.1 (VREFH); also elsewhere on the board
V_REFL: IC1.28 (VREFL); also elsewhere on the board

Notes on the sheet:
https://www.mouser.de/ProductDetail/3M-Electronic-Solutions-Division/8428-21B1-RK-TP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

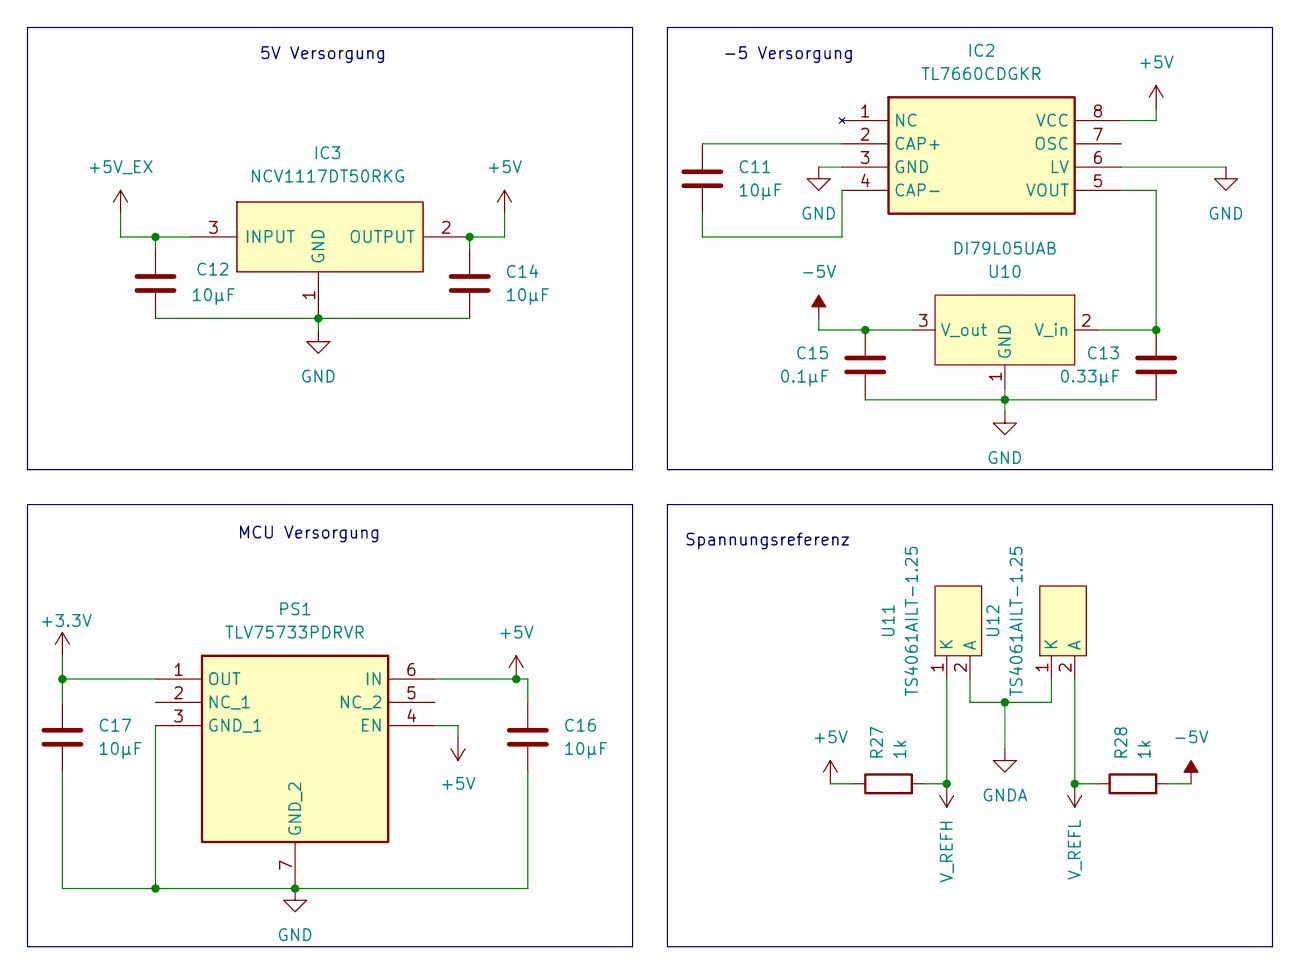
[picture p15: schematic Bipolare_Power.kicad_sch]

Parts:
C11, C12, C14, C16, C17: 10µF; C_0805_2012Metric_Pad1.18x1.45mm_HandSolder
C13: 0.33µF; C_0805_2012Metric_Pad1.18x1.45mm_HandSolder
C15: 0.1µF; C_0805_2012Metric_Pad1.18x1.45mm_HandSolder
IC2: TL7660CDGKR; SOP65P490X110-8N; Mouser Part Number 595-TL7660CDGKR
IC3: NCV1117DT50RKG; Mouser Part Number 863-NCV1117DT50RKG
PS1: TLV75733PDRVR; SON65P200X200X80-7N; Mouser Part Number 595-TLV75733PDRVR
R27, R28: 1k; R_0805_2012Metric_Pad1.20x1.40mm_HandSolder
U10: DI79L05UAB; SOT-89-3_Handsoldering
U11, U12: TS4061AILT-1.25; SOT-23-3

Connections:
+3.3V: C17.1, PS1.1 (OUT); also elsewhere on the board
+5V: C14.1, C16.1, IC2.8 (VCC), IC3.2 (OUTPUT), PS1.4 (EN), PS1.6 (IN), R27.1; also elsewhere on the board
+5V_EX: C12.1, IC3.3 (INPUT); also elsewhere on the board
-5V: C15.1, R28.2, U10.3 (V_out); also elsewhere on the board
GND: C12.2, C13.2, C14.2, C15.2, C16.2, C17.2, IC2.3 (GND), IC2.6 (LV), IC3.1 (GND), PS1.3 (GND_1), PS1.7 (GND_2), U10.1 (GND); also elsewhere on the board
GNDA: U11.2 (A), U12.1 (K); also elsewhere on the board
unnamed: C11.1, IC2.2 (CAP+)
unnamed: C11.2, IC2.4 (CAP-)
unnamed: C13.1, IC2.5 (VOUT), U10.2 (V_in)
V_REFH: R27.2, U11.1 (K); also elsewhere on the board
V_REFL: R28.1, U12.2 (A); also elsewhere on the board

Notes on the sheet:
5V Versorgung
Spannungsreferenz
-5 Versorgung
MCU Versorgung

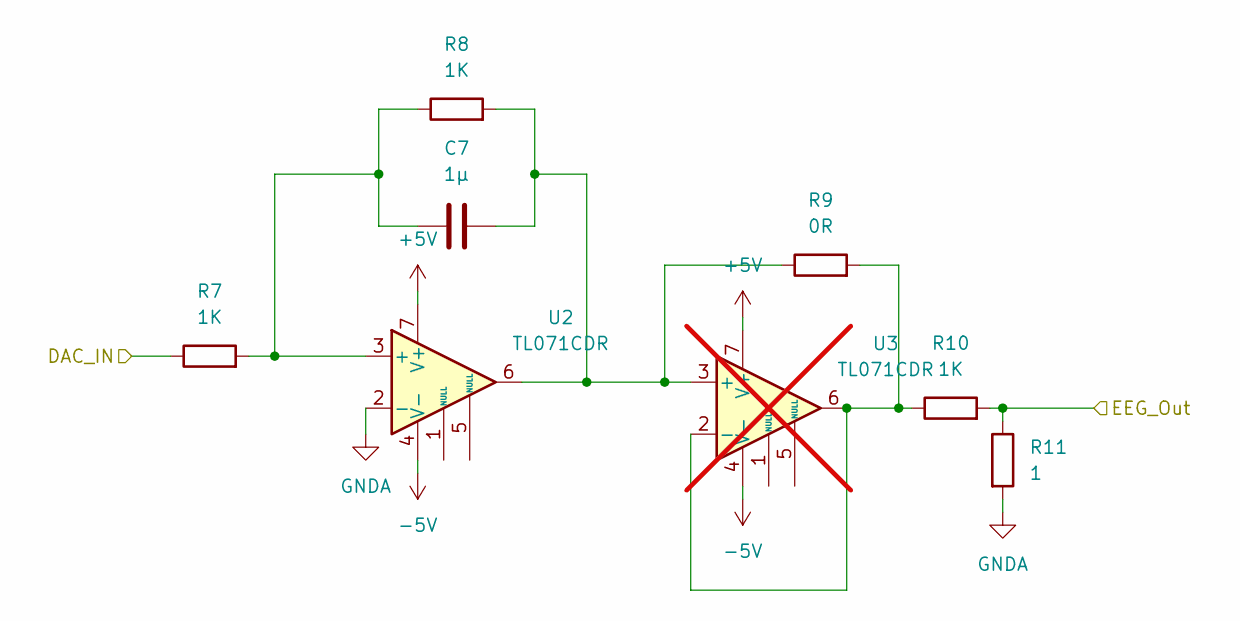
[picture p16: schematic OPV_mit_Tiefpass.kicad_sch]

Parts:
C7: 1µ; C_0805_2012Metric_Pad1.18x1.45mm_HandSolder
R7, R8, R10: 1K; R_0805_2012Metric_Pad1.20x1.40mm_HandSolder
R9: 0R; R_0805_2012Metric_Pad1.20x1.40mm_HandSolder
R11: 1; R_0805_2012Metric_Pad1.20x1.40mm_HandSolder
U2: TL071CDR; SOIC-8_4_5.3_combo_P1.27mm
U3: TL071CDR; SOIC-8_4_5.3_combo_P1.27mm; not fitted

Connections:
+5V: U2.7 (V+), U3.7 (V+); also elsewhere on the board
-5V: U2.4 (V-), U3.4 (V-); also elsewhere on the board
/OPV_mit_Tiefpass/EEG_Out: R10.2, R11.1; also elsewhere on the board
/VOUTA: R7.1; also elsewhere on the board
GNDA: R11.2, U2.2 (-); also elsewhere on the board
unnamed: C7.2, R7.2, R8.1, U2.3 (+)
unnamed: C7.1, R8.2, R9.1, U2.6, U3.3 (+)
unnamed: R9.2, R10.1, U3.2 (-), U3.6

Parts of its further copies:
C8, C9, C10: 1µ; C_0805_2012Metric_Pad1.18x1.45mm_HandSolder
R12, R13, R15, R17, R18, R20, R22, R23, R25: 1K; R_0805_2012Metric_Pad1.20x1.40mm_HandSolder
R14, R19, R24: 0R; R_0805_2012Metric_Pad1.20x1.40mm_HandSolder
R16, R21, R26: 1; R_0805_2012Metric_Pad1.20x1.40mm_HandSolder
U4, U6, U8: TL071CDR; SOIC-8_4_5.3_combo_P1.27mm
U5, U7, U9: TL071CDR; SOIC-8_4_5.3_combo_P1.27mm; not fitted

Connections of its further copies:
+5V: U4.7 (V+), U5.7 (V+), U6.7 (V+), U7.7 (V+), U8.7 (V+), U9.7 (V+); also elsewhere on the board
-5V: U4.4 (V-), U5.4 (V-), U6.4 (V-), U7.4 (V-), U8.4 (V-), U9.4 (V-); also elsewhere on the board
/OPV_mit_Tiefpass1/EEG_Out: R15.2, R16.1; also elsewhere on the board
/OPV_mit_Tiefpass2/EEG_Out: R20.2, R21.1; also elsewhere on the board
/OPV_mit_Tiefpass3/EEG_Out: R25.2, R26.1; also elsewhere on the board
/VOUTB: R12.1; also elsewhere on the board
/VOUTC: R17.1; also elsewhere on the board
/VOUTD: R22.1; also elsewhere on the board
GNDA: R16.2, R21.2, R26.2, U4.2 (-), U6.2 (-), U8.2 (-); also elsewhere on the board
unnamed: C8.2, R12.2, R13.1, U4.3 (+)
unnamed: C8.1, R13.2, R14.1, U4.6, U5.3 (+)
unnamed: R14.2, R15.1, U5.2 (-), U5.6
unnamed: C9.2, R17.2, R18.1, U6.3 (+)
unnamed: C9.1, R18.2, R19.1, U6.6, U7.3 (+)
unnamed: R19.2, R20.1, U7.2 (-), U7.6
unnamed: C10.2, R22.2, R23.1, U8.3 (+)
unnamed: C10.1, R23.2, R24.1, U8.6, U9.3 (+)
unnamed: R24.2, R25.1, U9.2 (-), U9.6

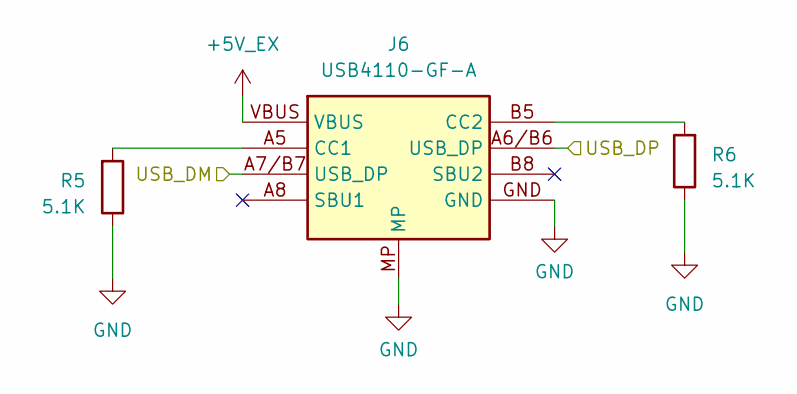
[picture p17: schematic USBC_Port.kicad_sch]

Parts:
J6: USB4110-GF-A; USB4110GFA; Mouser Part Number 640-USB4110-GF-A
R5, R6: 5.1K; R_0805_2012Metric_Pad1.20x1.40mm_HandSolder

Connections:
+5V_EX: J6.VBUS; also elsewhere on the board
/ESP32-S3/USB_DM: J6.A7/B7 (USB_DP); also elsewhere on the board
/ESP32-S3/USB_DP: J6.A6/B6 (USB_DP); also elsewhere on the board
GND: J6.GND, J6.MP, R5.1, R6.1; also elsewhere on the board
unnamed: J6.A5 (CC1), R5.2
unnamed: J6.B5 (CC2), R6.2

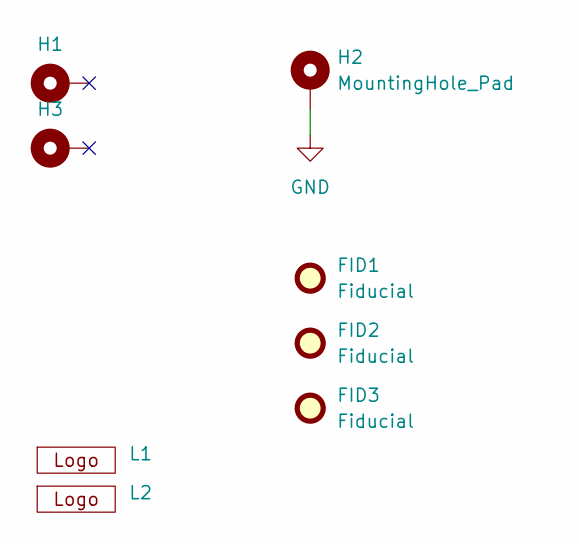
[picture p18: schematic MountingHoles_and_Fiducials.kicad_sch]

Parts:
FID1, FID2, FID3: Fiducial; Fiducial_1mm_Mask3mm
H1, H2, H3: MountingHole_Pad; MountingHole_3.2mm_M3_Pad_Via
L1: Fischi
L2: HS_Wismar_Corporate_Design

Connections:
GND: H2.1; also elsewhere on the board

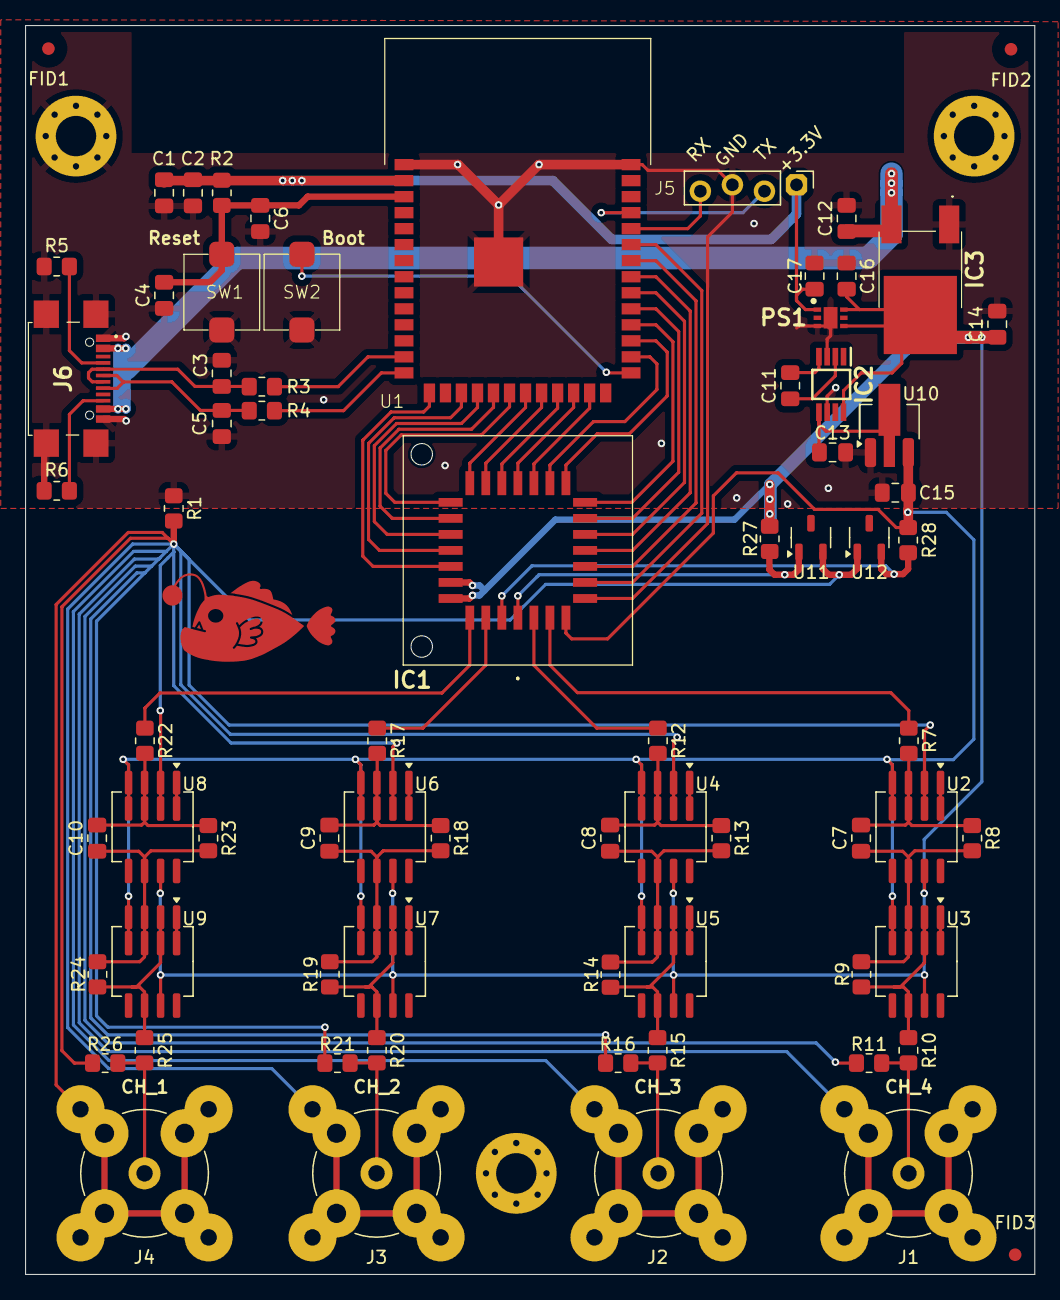
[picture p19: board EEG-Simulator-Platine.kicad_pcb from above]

Board: 2 copper layers, 80.0 x 99.0 mm, 77 parts (1 on the bottom side), 59 nets.

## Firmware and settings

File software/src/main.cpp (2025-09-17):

#include <Arduino.h>
#include <WiFi.h>
#include <esp_event.h>
#include <esp_netif.h>
#include <SPIFFS.h>
#include <ESPAsyncWebServer.h>
#include "Global_Var.hpp"
#include "Server.hpp"
#include "PinMapping.hpp"
#include "Spannungswandlung.hpp"

// Globale Serverinstanz
AsyncWebServer server(80);

std::map<String, std::vector<float>> kanalDaten;
std::vector<FileData> uploadedFiles;
std::map<AsyncWebServerRequest*, ActiveUpload> activeUploads;

extern void ladeFrequenzAusDatei();

void setup() {
  Serial.begin(115200);
  delay(1000);

  Serial.println("Pin Mapping initialisieren...");
  initPinModes();
  delay(100);
  Serial.println("DACs initialisieren...");
  digitalWrite(RST, LOW); // Reset des DACs
  delayMicroseconds(1);          // Setup-Zeit (tWS ≥ 0 ns)
  digitalWrite(RST, HIGH); // Reset des DACs beenden
  delay(100); // Warten, bis der Reset abgeschlossen ist
  Serial.println("Starte Netzwerkstack...");
  esp_netif_init();
  esp_event_loop_create_default();
  Serial.println("Initialisiere WiFi...");
  WiFi.mode(WIFI_AP);
  delay(250);  // wichtig!
  bool ok = WiFi.softAP("EEGsimulator", "EEGsimulator2525");
  delay(250);
  if (!ok) {
    Serial.println("❌ SoftAP-Start fehlgeschlagen!");
    while (true);
  }
  Serial.println("✅ SoftAP IP: " + WiFi.softAPIP().toString());
 Serial.println("WiFi Passwort: EEGsimulator2525");

  Serial.println("Initialisiere SPIFFS...");
  if (!SPIFFS.begin(true)) {
    Serial.println("❌ SPIFFS Fehler");
    while (true);
  }

  delay(100);

  Serial.println("Lade Frequenz aus Datei...");
  ladeFrequenzAusDatei();

  delay(100);


  Serial.println("Starte Webserver...");
  setupWebServer();
  server.begin();
  Serial.println("✅ Webserver aktiv.");
}

void loop() {
  delay(10); // Leerlauf mit RTOS-Kooperation
}

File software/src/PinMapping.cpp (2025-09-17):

#include <Arduino.h>
#include "PinMapping.hpp"

void initPinModes() {
  // Datenleitungen
  pinMode(DB0, OUTPUT);
  pinMode(DB1, OUTPUT);
  pinMode(DB2, OUTPUT);
  pinMode(DB3, OUTPUT);
  pinMode(DB4, OUTPUT);
  pinMode(DB5, OUTPUT);
  pinMode(DB6, OUTPUT);
  pinMode(DB7, OUTPUT);
  pinMode(DB8, OUTPUT);
  pinMode(DB9, OUTPUT);
  pinMode(DB10, OUTPUT);
  pinMode(DB11, OUTPUT);

  // Adressleitungen
  pinMode(ADD0, OUTPUT);
  pinMode(ADD1, OUTPUT);

  // Steuerleitungen
  pinMode(RST, OUTPUT);
  pinMode(Load_Data, OUTPUT);
  pinMode(R_W, OUTPUT);
  pinMode(CS, OUTPUT);
  digitalWrite(CS, HIGH); // Inaktiv setzen
  
}
